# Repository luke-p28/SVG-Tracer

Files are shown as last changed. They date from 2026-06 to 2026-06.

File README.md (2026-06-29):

# Laser Pointer SVG Tracer

## Purpose
Hosts a web server on an ESP where users can upload SVG files.
Controls 2 servos to trace the SVG on the ground with an attached laser pointer.

## Assembly
This project consists of 3D-printed and electrical parts. The servo mount is 3D-printed and assembled as shown here.



The 2 9G micro servos are lightly hot-glued into their respective pockets, and the two gears are hot-glued to the servo horns.

Note: if anyone actually wants to build this, they would likely have to design their own laser pointer mount, since I just used a random laser pointer I had lying around and have no clue what brand it is.

## Wiring
The positive pins on the 9G servos are connected to pin wires, which are soldered to the positive terminal of a 3x AA battery mount. The negative pins are likewise connected to the negative terminal of the battery mount, but are also connected to the ground pin of a NodeMCU 1.0 ESP-12E module. The Z-axis servo (the lower one) has its PWM pin connected to D5 on the ESP, while the Y-axis servo (the upper one) is connected to the D6 pin.

## Config
The code uses a config.h file for WiFi credentials. It should declare two constant String variables, one named 'ssid' and one named 'password', and be placed next to main.ino in the main directory.

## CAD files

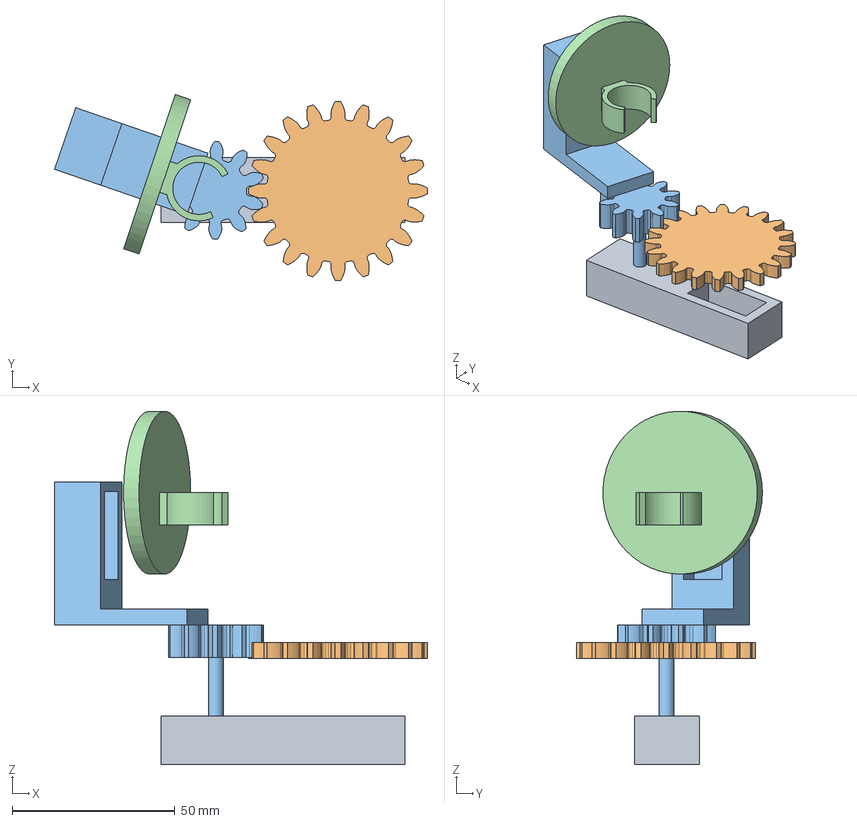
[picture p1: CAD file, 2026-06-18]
CAD/SVG Tracer.FCStd
114.6 x 57.1 x 108.5 mm
Base
Big Gear
Small Gear
Laser Pointer Mount

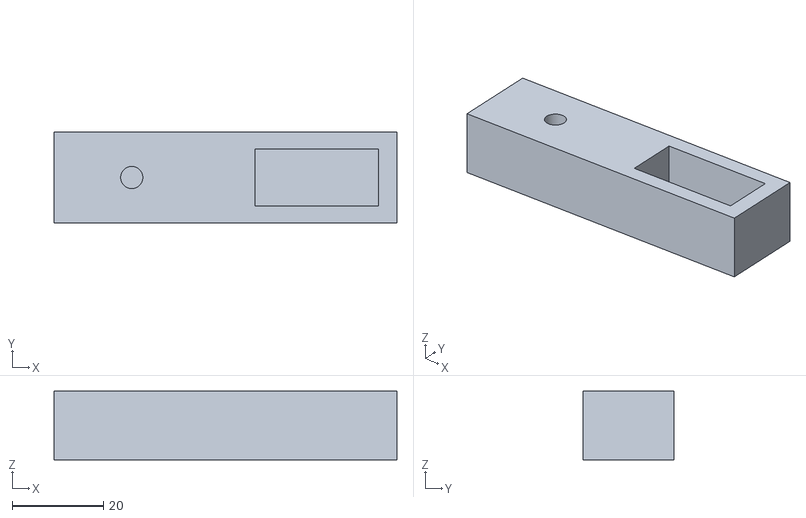
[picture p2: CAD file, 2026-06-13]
CAD/Base.stl
75.0 x 20.0 x 15.0

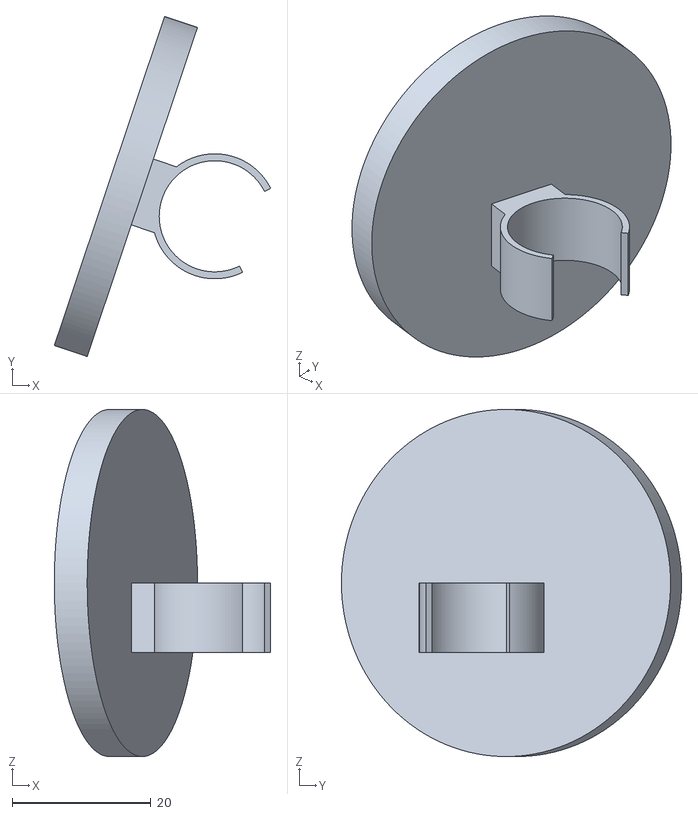
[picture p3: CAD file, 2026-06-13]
CAD/Laser Pointer Mount.stl
31.2 x 49.0 x 50.0

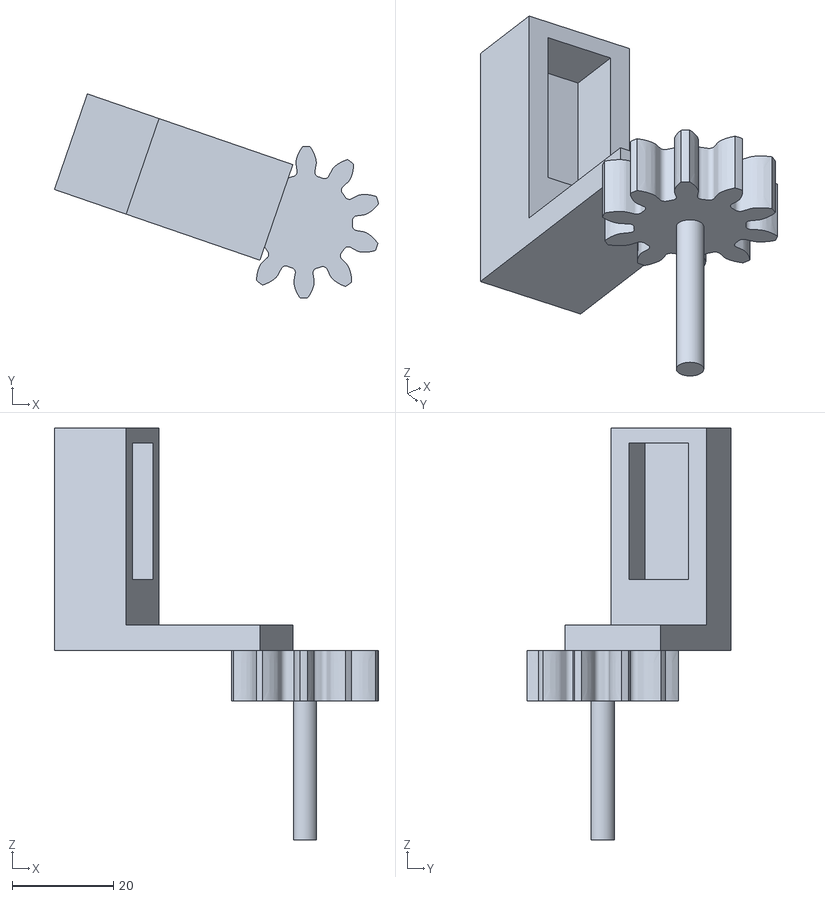
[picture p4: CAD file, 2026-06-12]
CAD/Small Gear.stl
64.1 x 40.4 x 81.5

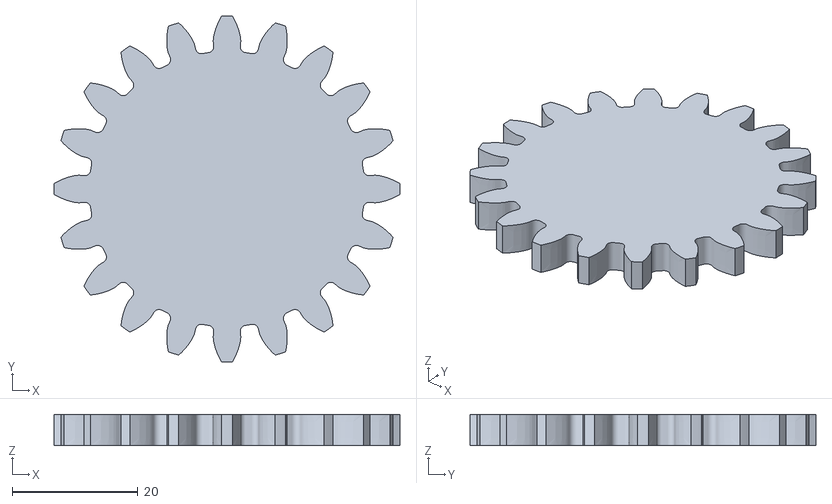
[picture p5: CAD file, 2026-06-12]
CAD/Big Gear.stl
55.0 x 55.0 x 5.00

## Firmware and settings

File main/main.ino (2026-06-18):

/*
Laser Pointer SVG Tracer
Made by Luke Powell on June 16th, 2026
Purpose:
Hosts a webserver on an ESP where users can upload SVG files.
Controls 2 servos to trace the SVG on the ground with an attached laser pointer.
*/

// ESP WiFi Library
#include <ESP8266WiFi.h>
// ESP Web Server Library
#include <ESP8266WebServer.h>
// Micro servo library
#include <Servo.h>
// Config for WiFi network SSID and password
#include "config.h"

// Initializes the web server object
auto server = ESP8266WebServer(80);
// Holds the name of the uploaded file
String fileName = "";
// Stores the contents of the uploaded file
String file = "";

// Servo object for the bottom servo (Z axis)
Servo servo_z;
// Servo object for the upper servo (Y axis)
Servo servo_y;
// Stores the height of the centre of the upper servo's horn in milimeters
const double y_servo_height = 70;

// Returns the HTML for the user interface website
String html(){
  String output = ""
  "<html>"
  "<body>"
  "<form action='/upload' method='POST' enctype='multipart/form-data'>"
  "<input type='file' name='file' required>"
  "<input type='submit' value='Upload'>"
  "</form>";
  // Inserts the name of the last uploaded file
  output += fileName == "" ? "No file uploaded" : "File name: " + fileName;
  output += ""
  "<br><br>"
  "<button> <a href='/redo' style='color: black; text-decoration: none;'> Redo Trace </a> </button>"
  "</body>"
  "</html>";
  return output;
}

// Takes a string of SVG code and draws it using the laser pointer
void draw_svg(String svg){
  // Saves the index of where the points of the path start
  const int index = svg.indexOf("points=", svg.indexOf("<polyline")) + 8;
  // Stores the string of the current number being parsed
  String curNum;
  // Stores true if the X coordinate of the current point has already been processed, false otherwise
  bool hasXCoord = false;
  // Stores true if the current point is the first one processed
  bool first = true;
  // Store the coordinates of the last point
  double lastX;
  double lastY;
  // Stores the current X coordinate
  double xCoord = 0;

  // Loops through the characters of the points list section of the string
  for(int i = index; i < svg.indexOf("\"", index); ++i){
    if (svg[i] == ' '){
      // If the current character is space, processes the next number

      if (hasXCoord){
        // If this is the Y coordinate, moves the laser pointer to that point

        Serial.print("Coordinates processed: ");
        Serial.print(xCoord);
        Serial.print(", ");
        Serial.println(curNum.toDouble());
        if (first){
          // If this is the first coordinate, moves the laser pointer directly there

          point_to_coords(-xCoord*0.353, (1100-curNum.toDouble())*0.353);
          // Delays for 1s
          delay(1000);
          // It's no longer the first one
          first = false;
        } else {
          // If this is not the first coordinate, moves the laser pointer there in 20 steps over 0.6s

          // Calculates the X and Y steps by dividing the difference by 20
          const int stepX = (-xCoord*0.353 - lastX)/20;
          const int stepY = ((1100-curNum.toDouble())*0.353 - lastY)/20;

          // Loops from 1 to 20 and moves to the corresponding step each time
          for (int i = 1; i <= 20; i++){
            point_to_coords(lastX + stepX*i, lastY + stepY*i);
            delay(30);
          }

          // Waits half a second at vertices
          delay(500);
        }

        // Updates the last coordinate values
        lastX = -xCoord*0.353;
        lastY = (1100-curNum.toDouble())*0.353;

        // The X coordinate is next
        hasXCoord = false;
      } else {
        // If this is the X coordinate, saves it and moves onto the Y coordinate

        hasXCoord = true;
        xCoord = curNum.toDouble();
      }

      // When a number is parsed, resets the curNum string
      curNum = "";
    } else 
    // Appends the current character to the curNum string
      curNum += svg[i];
  }

  Serial.print("Coordinates processed: ");
  Serial.print(xCoord);
  Serial.print(", ");
  Serial.println(curNum.toDouble());

  // Calculates the X and Y steps by dividing the difference by 20
  const int stepX = (-xCoord*0.353 - lastX)/20;
  const int stepY = ((1100-curNum.toDouble())*0.353 - lastY)/20;
  
  // Loops from 1 to 20 and moves the laser pointer to the corresponding step each time
  for (int i = 1; i <= 20; i++){
    point_to_coords(lastX + stepX*i, lastY + stepY*i);
    delay(30);
  }
}

// Converts an angle from radians to an angle in degrees from 0 to 360
double process_angle(double rad){
  // Converts to degrees
  double output = rad*180/PI;
  // Uses the co-terminal angle between 0 and 360
  while (output < 0){
    output += 360;
  }
  // Returs the processed angle
  return output;
}

// Calculates the angle for the Z axis servo to point to the given coordinates
double z_angle(double x, double y){
  // Uses inverse tangent ratio between the Y and X coordinates
  return process_angle(atan2(y, x))/2;
}

// Calculates the angle for the Y axis servo to point to the given coordinates
double y_angle(double x, double y) {
  // Uses inverse tangent ratio between the XY plane distance and the Y servo's height
  return process_angle(atan2(sqrt(x*x + y*y), y_servo_height));
}

// Points both servos to the given coordinates
void point_to_coords(double x, double y){
  // Prints the current plane coordinates
  Serial.print("Pointing to: ");
  Serial.print(x);
  Serial.print(", ");
  Serial.println(y);
  // Prints the Z and Y angles
  Serial.print("Z angle: ");
  Serial.print(z_angle(x, y));
  Serial.print(", Y angle: ");
  Serial.println(y_angle(x,y));

  // Sets the Z servo to the Z angle and the Y servo to the Y angle
  servo_z.write(z_angle(x, y));
  servo_y.write(y_angle(x, y));
}

// Runs once when the code starts
void setup(){
  // Sets up the Z axis servo on the D5 pin and the Y axis servo on the D6 pin
  servo_z.attach(D5, 600, 2400);
  servo_y.attach(D6, 550, 2450);

  // Sets up the pin connected to the onboard LED for output mode
  pinMode(D0, OUTPUT);

  // Initializes the serial connection
  Serial.begin(115200);

  // Begins connecting to WiFi as configured in config.h
  WiFi.mode(WIFI_STA);
  WiFi.begin(ssid, password);

  // Blinks the onboard LED while WiFi is connecting
  while (WiFi.status() != WL_CONNECTED){
    digitalWrite(D0, LOW);
    delay(800);
    digitalWrite(D0, HIGH);
    delay(100);
  }

  // Turns on onboard LED after WiFi has connected
  digitalWrite(D0, LOW);
  
  // Sends the website HTML at the root address of the website
  server.on("/", [](){server.send(200, "text/html", html());});

  // Handles upload of SVG files
  server.on("/upload", HTTP_POST, [](){Serial.println("Uploaded");}, [](){
    if (server.upload().status == UPLOAD_FILE_START){
      // If this event is the start of the upload, saves the file name and resets the file variable

      Serial.println(server.upload().filename);
      fileName = server.upload().filename;
      file = "";

    } else if (server.upload().status == UPLOAD_FILE_WRITE){
      // If this event is file text, adds it to the file object

      // Loops through all bytes in the buffer
      for (auto e : server.upload().buf){
        // If the character from the current byte is not a new line, appends it to the file variable
        if ((char)e != '\n'){
          file += (char)e;
        }
      }
    } else if (server.upload().status == UPLOAD_FILE_END){
      // If this event is the end of the file upload, commences SVG tracing

      // Prints the contents of the file to the serial monitor
      Serial.print("File: '");
      Serial.print(file);
      Serial.println("'");

      // Traces the file
      draw_svg(file);

      // Redirects the user to the home page
      server.sendHeader("Location", "/");
      server.send(303);
    }
  });

  // When the user presses the redo button, runs the trace again and redirects to the home page
  server.on("/redo", [](){
    draw_svg(file);
    server.sendHeader("Location", "/");
    server.send(303);
  });

  // Starts up the server
  server.begin();

  // Prints the local IP address to the serial monitor
  Serial.println();
  Serial.print("IP: ");
  Serial.println(WiFi.localIP());

  // Points to 100, 100 mm for calibration
  point_to_coords(100, 100);
}

// Runs indefinitely
void loop(){
  // Handles incoming web requests to the server
  server.handleClient();
}

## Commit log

2026-06-10 Servo mount v1
    3D print files to mount the servo are hopefully functional, but there's no spot for the Arduino or wires.
    [SVG Tracer.FCStd]
2026-06-11 Servo Pocket Adjustments and Gear Repositioning
    Slightly increased the space for the servo wires to avoid lifespan reduction and fixed an issue where the small gear placement did not take into account the wires.
    [Base.stl, Big Gear.stl, Laser Pointer Mount.stl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]
2026-06-12 Started code
    Made ESP code to host a basic webserver where you can upload a file and the code will process it as a string
    [Base.stl, Big Gear.stl, Laser Pointer Mount.stl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]
2026-06-12 Gear Clearance Fix
    Made the small gear taller so that the y servo mount would fully clear the big gear, and increased the size of the laser pointer mount to increase lifespan
    [Laser Pointer Mount.stl, SVG Tracer.FCStd, Small Gear.stl]
2026-06-13 Clearance adjustments, servo code, and SVG parsing
    Adjusted the gear spacing on the base, reduced the clearance between the small gear shaft and the pocket in the base, modified the thickness of the laser point mount to allow it to bend better, added code to control the servos to point to coordinates on the XY plane, and implemented parsing of SVG polyline points.
    [Base.stl, Laser Pointer Mount.stl, SVG Tracer.FCStd]
2026-06-15 It works...?
    Did some tuning of PWM values for the servos, translated and scaled the image being drawn to match the original, and switched from atan to atan2 in order to avoid quadrant ambiguity.
    [main.ino]
2026-06-15 Real-world units
    Converted from pixels to millimeters in SVG parsing, to allow closer to real-world visualization of vectors
2026-06-15 Added redo
    Made a button that traces the last shape uploaded
2026-06-18 Commenting
    Removed some unnecessary code and added comments
    [SVG Tracer.FCStd]
2026-06-29 Added readme.md
    Added a readme that described the purpose, assembly, wiring, and config of the project.
